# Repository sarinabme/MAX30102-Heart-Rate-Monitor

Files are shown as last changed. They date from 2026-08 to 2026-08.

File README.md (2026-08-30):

# Arduino Heart Rate Monitor❤️

> A real-time heart rate monitoring prototype using **Arduino UNO** and the **MAX30102 PPG sensor**.

<br>

## Overview

This project is an **Arduino-based heart rate monitoring prototype** developed using the **Arduino UNO** and the **MAX30102 optical pulse sensor**.

The system measures pulse signals using **photoplethysmography (PPG)**, calculates heart rate in **beats per minute (BPM)**, and displays the average measurement on a **16×2 I2C LCD**.

Based on **predefined BPM thresholds**, the measured heart rate is classified as **NORMAL**, **BRADYCARDIA**, or **TACHYCARDIA**. An audible **buzzer** provides feedback when the measured value falls outside the predefined normal range.

The prototype is designed as an **educational biomedical engineering project** to demonstrate the integration of **biosensors, microcontrollers, real-time signal acquisition, user feedback, and basic heart-rate classification**.

<br>

## 📸 Project Media

### 🧩 Hardware Setup

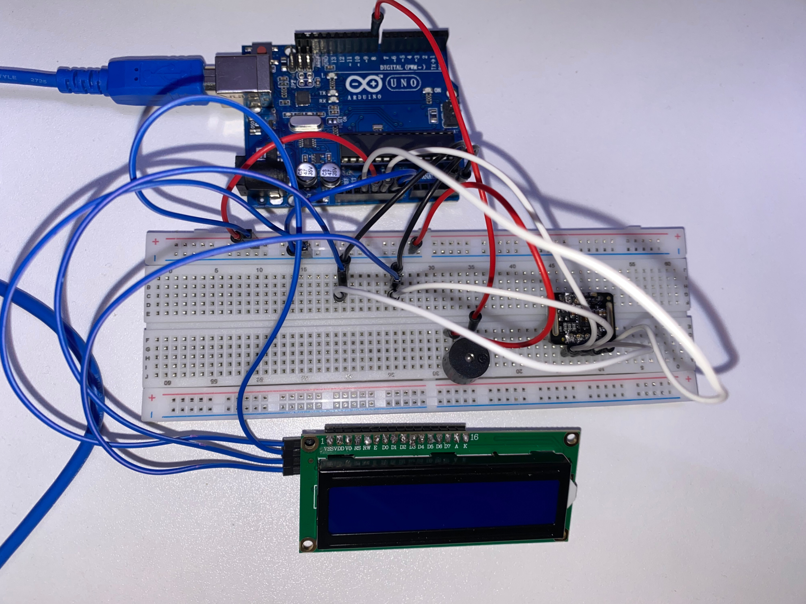
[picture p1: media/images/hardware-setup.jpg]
Hardware Setup


The complete prototype, including the **Arduino UNO, MAX30102 pulse sensor, 16×2 I2C LCD, buzzer, breadboard, and connecting wires**.

### ⚙️ System Initialization

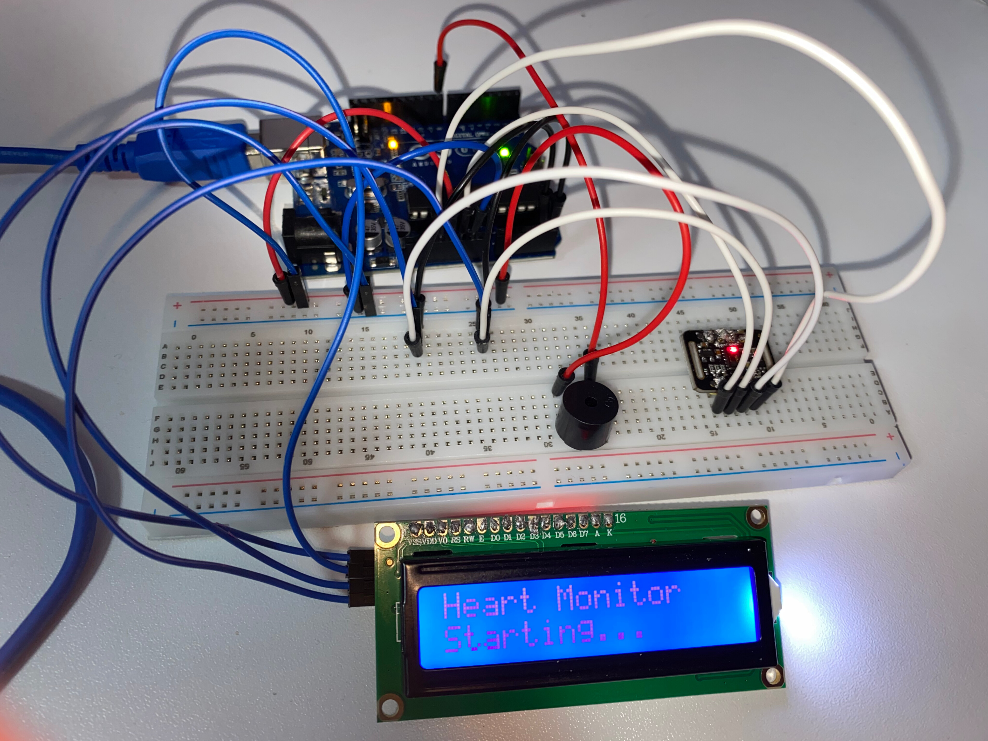
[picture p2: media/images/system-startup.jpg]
System Initialization


The system initializes the heart-rate monitoring hardware and prepares the sensor for measurement.

### ❤️ Real-Time Measurement

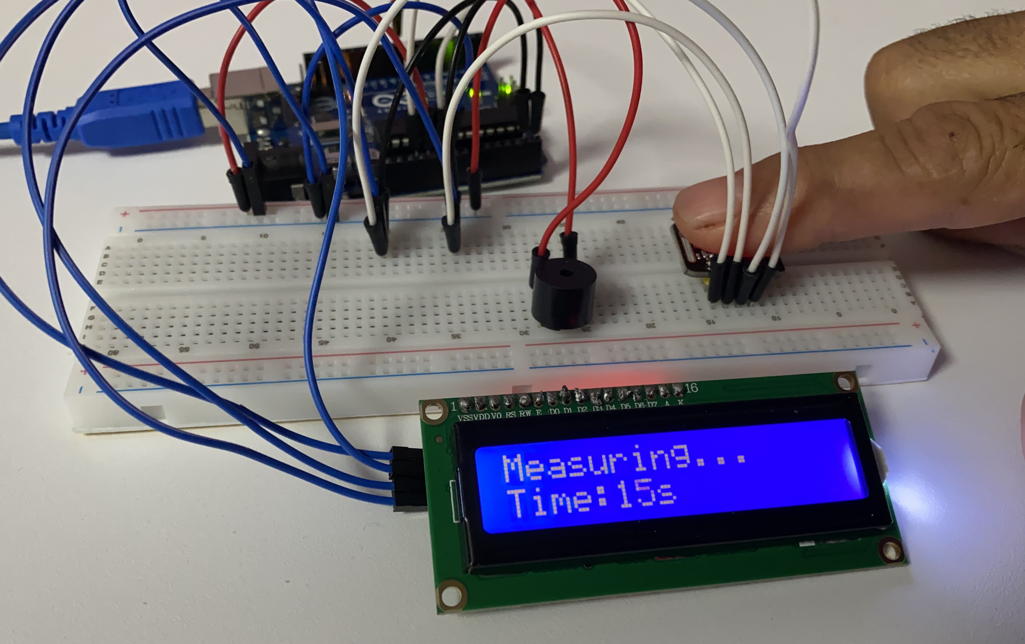
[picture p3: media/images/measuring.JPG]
Real-Time Measurement


During the measurement phase, the system continuously acquires pulse data while displaying the **remaining measurement time** on the LCD.

### 🔎 Data Analysis

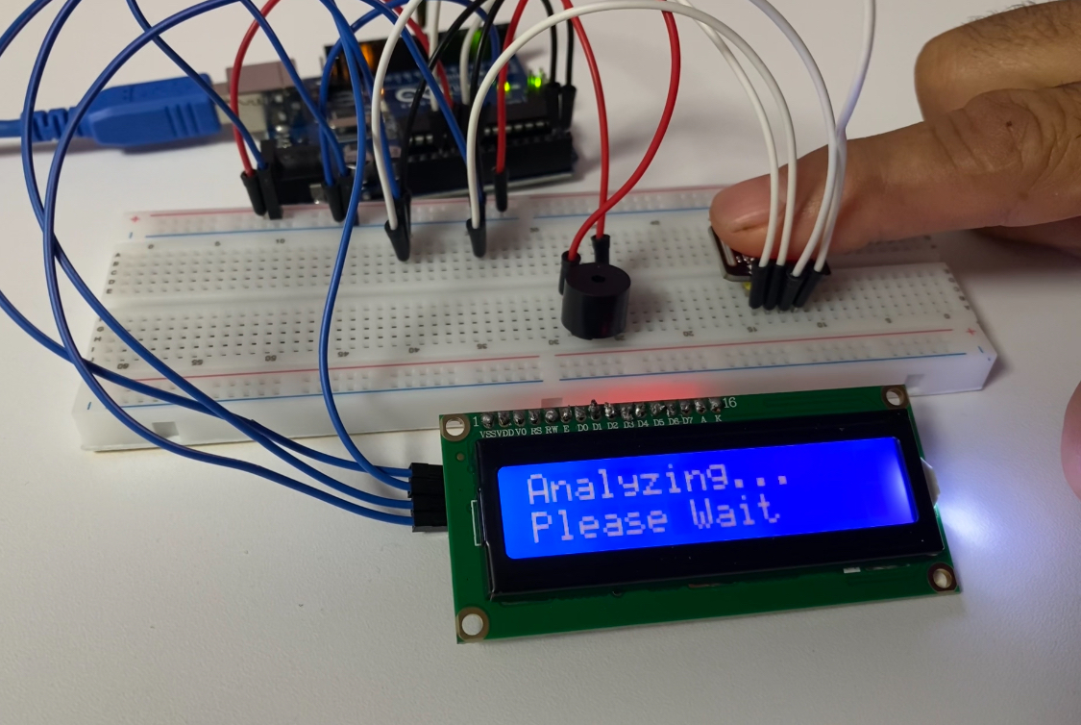
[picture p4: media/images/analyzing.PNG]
Data Analysis


After the **20-second measurement window**, the collected BPM data is processed to calculate the **average heart rate**.

### 📊 Normal Heart Rate Results

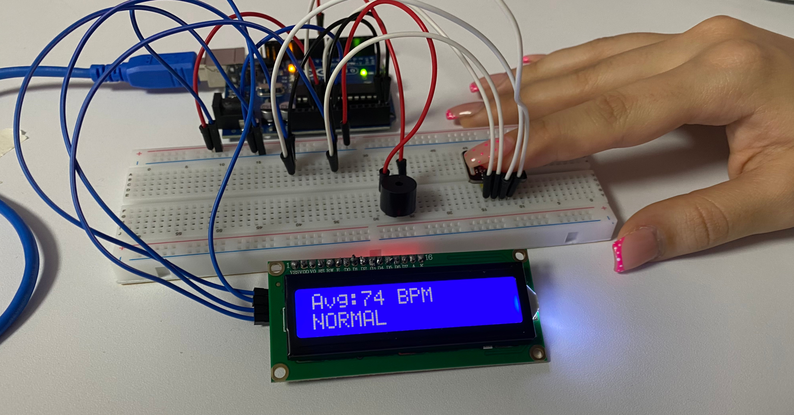
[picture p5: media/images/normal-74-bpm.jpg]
74 BPM Normal


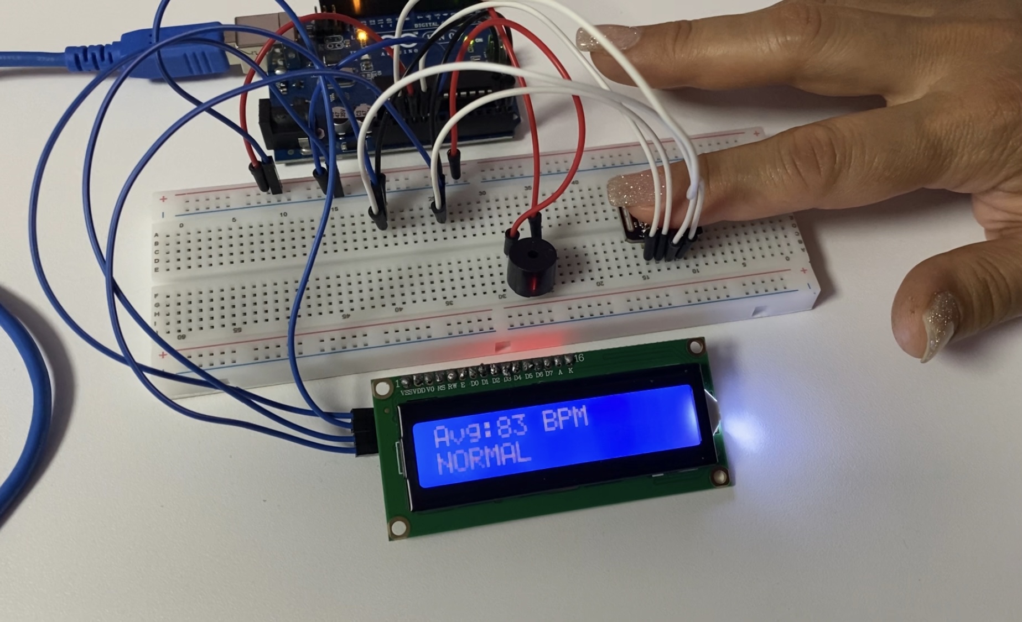
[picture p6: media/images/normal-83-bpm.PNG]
83 BPM Normal


Example measurements classified as **NORMAL** according to the predefined BPM thresholds implemented in the program.

### 🎥 Demonstration Videos

#### Bradycardia Detection

[▶️ Watch the Bradycardia Detection Demo](media/videos/bradycardia-detection.mp4)

Demonstration of a low heart-rate measurement resulting in a **`BRADYCARDIA`** classification and an audible **buzzer alert**.

#### Full Measurement Cycle

[▶️ Watch the Full Measurement Cycle](media/videos/full-measurement-cycle.mp4)

Demonstration of the measurement workflow, from **system initialization and finger detection** to **BPM calculation, classification, and test reset**.

#### No Reading Handling

[▶️ Watch the No Reading Demo](media/videos/no-reading-handling.mp4)

Demonstration of the system response when **no valid heart-rate measurement is obtained**.

<br>

## ✨ Features

*  **Real-Time Heart Rate Monitoring** using the MAX30102 optical pulse sensor
*  **BPM Calculation** from detected pulse intervals
*  **Average BPM Calculation** over a 20-second measurement window
*  **16×2 I2C LCD Display** for real-time system status and measurement results
*  **Measurement Countdown** displayed during the acquisition process
*  **Audible Feedback** using a buzzer for system status and heart-rate alerts
*  **Heart-Rate Classification** based on predefined BPM thresholds
*  **No Finger Detection** with a 30-second timeout
*  **No Reading Handling** when no valid BPM data is obtained
*  **Automatic Test Reset** with a countdown before starting a new measurement
*  **Serial Monitor Output** for debugging and BPM monitoring

<br>

## 🔧 Hardware

* **Arduino UNO** — Microcontroller
* **MAX30102** — Optical pulse sensor (PPG)
* **16×2 LCD** — User interface and result display
* **I2C Module** — Serial communication interface for the LCD
* **Buzzer** — Audible status and alert feedback
* **Breadboard** — Prototyping platform
* **Jumper Wires** — Electrical connections
* **Pin Headers** — Component connections
* **USB-B Cable** — Arduino power and programming

<br>

## 🧠 Architecture

The system follows a simple real-time acquisition and processing architecture.

The **MAX30102** captures optical pulse signals using photoplethysmography (PPG). The acquired data is processed by the **Arduino UNO**, which detects heartbeats, calculates BPM values, and computes the average heart rate over the measurement window.

The calculated result is then classified according to predefined BPM thresholds. The **16×2 I2C LCD** provides visual feedback throughout the measurement process, while the **buzzer** provides audible status and alert feedback.

### System Flow

**MAX30102 → Signal Acquisition → Beat Detection → BPM Calculation → Averaging → Heart-Rate Classification → LCD / Buzzer Output**

<br>

## ⚙️ How It Works

```text
System Initialization
        ↓
   Place Finger
        ↓
20-Second Measurement
        ↓
   Beat Detection
        ↓
   BPM Calculation
        ↓
    Averaging
        ↓
Heart-Rate Classification
        ↓
 LCD + Buzzer Output
        ↓
  New Test Countdown
```

<br>

## 📐 BPM Algorithm

The heart rate is estimated from the pulse signal acquired by the **MAX30102 PPG sensor**.

### Beat Detection

During the measurement window, the Arduino continuously reads the sensor's infrared (IR) signal. Individual heartbeats are detected using the `checkForBeat()` function provided by the MAX30102 heart-rate library.

When a heartbeat is detected, the system records its timestamp using `millis()`.

The time interval between two consecutive detected beats is calculated as:

**Δt = t₂ − t₁**

where:

* **t₁** = timestamp of the previous detected beat
* **t₂** = timestamp of the current detected beat
* **Δt** = time interval between consecutive beats in milliseconds

### Instantaneous BPM

The instantaneous heart rate is calculated from the beat-to-beat interval:

**BPM = 60,000 / Δt**

The factor **60,000** converts milliseconds to minutes.

Only calculated BPM values within the programmed range of **20–220 BPM** are accepted for averaging.

### Average BPM

During the **20-second measurement window**, all valid instantaneous BPM values are accumulated.

The final average is calculated as:

**Average BPM = Sum of valid BPM values / Number of valid BPM values**

If no valid BPM values are detected during the measurement period, the system displays:

`No Reading`

This approach provides a simple average of the detected beat-to-beat heart-rate estimates over the measurement window.

<br>

## ❤️ Heart Rate Classification

The calculated average BPM is classified using predefined thresholds implemented in the program.

| Average BPM  | Classification  | Buzzer |
| :---: | :--- | :--- |
|  **< 60 BPM**  | **BRADYCARDIA** | Continuous alert |
| **60–100 BPM** | **NORMAL** | Short confirmation beep |
|  **> 100 BPM** | **TACHYCARDIA** | Continuous alert |

The classification is based solely on the predefined BPM thresholds used in this prototype. It is intended for **educational demonstration and basic heart-rate classification**, not medical diagnosis.

### Classification Logic

```text
Average BPM
     │
     ├── < 60 ────────→ BRADYCARDIA
     │
     ├── 60–100 ──────→ NORMAL
     │
     └── > 100 ───────→ TACHYCARDIA
```

<br>

## 🔌 Wiring

The MAX30102 sensor and the 16×2 LCD communicate with the Arduino UNO through the **I²C interface**.

### Pin Connections

| Component | Pin | Arduino UNO |
| :--- | :----- | :---: |
| **MAX30102** | SDA | A4 |
| **MAX30102** | SCL | A5 |
| **MAX30102** | VCC | 3.3V |
| **MAX30102** | GND | GND |
| **16×2 I2C LCD** | SDA | A4 |
| **16×2 I2C LCD** | SCL | A5 |
| **16×2 I2C LCD** | VCC | 5V |
| **16×2 I2C LCD** | GND | GND |
| **Buzzer** | Signal | D8 |
| **Buzzer** | GND | GND |

### I²C Configuration

The LCD is initialized using the I²C address:

```cpp
LiquidCrystal_I2C lcd(0x27, 16, 2);
```

Both the MAX30102 and the LCD share the Arduino UNO's I²C bus through **SDA (A4)** and **SCL (A5)**.

> **Note:** The I²C address `0x27` is specific to the LCD I²C module used in this prototype and may differ between modules.

### Fritzing Wiring Diagram

The following diagram illustrates the complete hardware wiring of the prototype, including the Arduino UNO, MAX30102 sensor, 16×2 I2C LCD, buzzer, breadboard, power connections, and I2C communication lines.

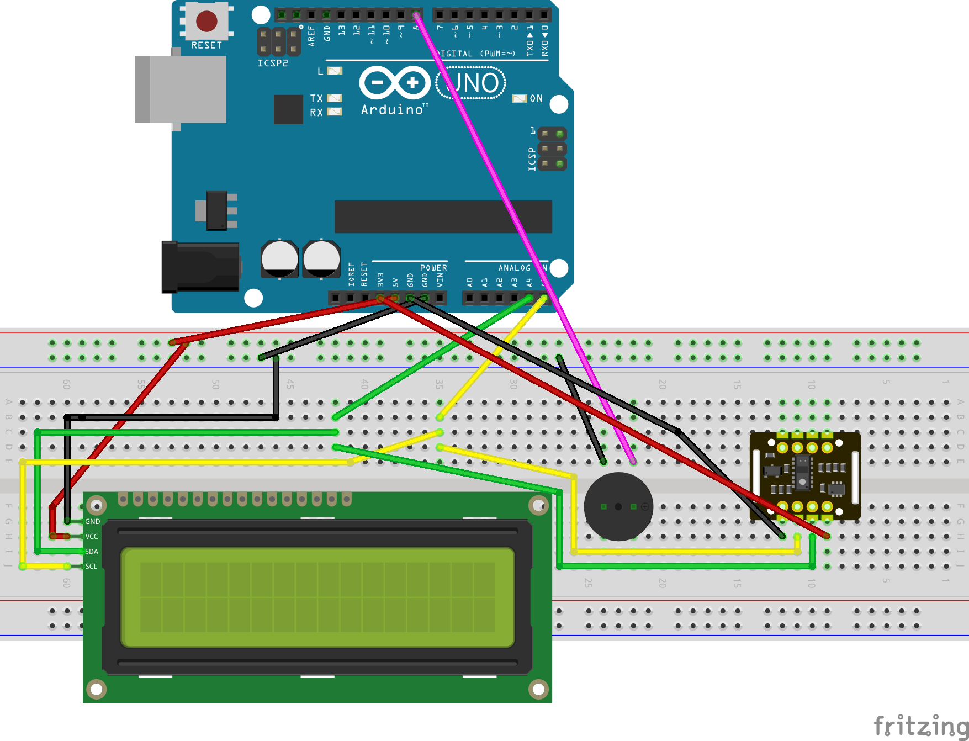
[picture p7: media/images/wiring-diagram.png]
Fritzing Wiring Diagram

<br>

## 💻 Installation

### 1. Install Arduino IDE

Install the **Arduino IDE** on your computer.

### 2. Connect the Arduino UNO

Connect the Arduino UNO to the computer using the **USB-B cable**.

### 3. Install Required Libraries

The project requires the following libraries:

* `Wire.h`
* `LiquidCrystal_I2C.h`
* `MAX30105.h`
* `heartRate.h`

`Wire.h` is included with the Arduino environment. The other libraries should be installed through the Arduino Library Manager or added manually if required.

### 4. Open the Project

Open the Arduino source file:

```text
src/HeartRateMonitor.ino
```

### 5. Select the Board and Port

In Arduino IDE:

**Tools → Board → Arduino UNO**

Then select the appropriate serial port under:

**Tools → Port**

### 6. Upload the Code

Compile and upload the program to the Arduino UNO.

After uploading, the system is ready for operation.

<br>

## ▶️ Usage

Follow these steps to perform a heart-rate measurement:

1. Power on the Arduino UNO.
2. Wait for the system initialization message.
3. When the LCD displays **`Place Finger / Ready...`**, place a finger gently on the MAX30102 sensor.
4. Wait for the short confirmation beep indicating that the finger has been detected.
5. Keep the finger stable during the **20-second measurement window**.
6. The LCD displays the remaining measurement time.
7. After measurement, the system displays **`Analyzing... / Please Wait`** while processing the collected data.
8. The final average BPM and classification are displayed on the LCD.
9. If the result is classified as **BRADYCARDIA** or **TACHYCARDIA**, the buzzer provides an audible alert.
10. After **7 seconds**, the system performs a **5-second countdown** and automatically prepares for a new measurement.

### Example LCD Flow

```text
Heart Monitor
Starting...
       ↓
Place Finger
Ready...
       ↓
Measuring...
Time: 15s
       ↓
Analyzing...
Please Wait
       ↓
Avg: 74 BPM
NORMAL
       ↓
New Test In
5 sec
```

<br>

## 🧪 Testing

The prototype was tested under several operating conditions to evaluate its basic functionality and response to different measurement scenarios.

| Test Case | Condition | Expected Behavior |
| :--- | :--- | :--- |
| **System Startup** | Arduino powered on | Display initialization message |
| **Finger Detection** | Finger placed on MAX30102 | Measurement begins |
| **No Finger** | No finger detected for 30 seconds | Display `No Finger / Try Again` |
| **Heart Rate Measurement** | Valid pulse signal detected | BPM values are calculated |
| **Normal Range** | Average BPM between 60–100 | Display `NORMAL` |
| **Low BPM** | Average BPM below 60 | Display `BRADYCARDIA` + buzzer alert |
| **High BPM** | Average BPM above 100 | Display `TACHYCARDIA` + buzzer alert |
| **Invalid Measurement** | No valid BPM obtained | Display `No Reading` |
| **Measurement Reset** | Test completed | 5-second countdown before new test |

These tests were designed to verify the main functional states implemented in the program, including normal operation, user interaction, abnormal classification, and basic error handling.

<br>

## 📊 Results

The prototype was successfully tested through multiple measurement scenarios. The observed outputs demonstrate the implemented measurement, classification, alert, and error-handling behaviors.

### Normal Measurements

Two example measurements produced results within the predefined normal range:

| Test | Average BPM | Classification |
| :--: | ---: | :--- |
| 1  |  **74 BPM** | **NORMAL** |
| 2  |  **83 BPM** | **NORMAL** |

### Low Heart-Rate Classification

Additional tests produced:

| Test | Average BPM | System Classification |
| :--: | ---: | :--- |
| 3  |  **58 BPM** | **BRADYCARDIA** |
| 4  |  **27 BPM** | **BRADYCARDIA** |

In both cases, the buzzer was activated according to the programmed alert logic.

### No Reading Test

A separate test resulted in:

```text
Analyzing...
Please Wait
        ↓
No Reading
```

This demonstrates that the system does not display an average BPM when no valid heart-rate data is obtained.

> **Important:** The values above represent prototype measurements and software classifications. They should not be interpreted as clinical measurements or medical diagnoses.

<br>

## ⚠️ Limitations

As an educational prototype, the system has several technical and practical limitations:

1. **Motion Artifacts**
   Finger movement can introduce artifacts into the PPG signal and may affect beat detection and BPM estimation.

2. **Finger Placement**
   Incorrect or inconsistent finger placement on the MAX30102 may reduce signal quality and affect the measurement.

3. **Ambient Light**
   External light conditions may influence optical measurements and reduce signal reliability.

4. **Short Measurement Window**
   The system uses a **20-second measurement window**, which is suitable for demonstrating the prototype but is not sufficient for comprehensive or long-term clinical monitoring.

5. **Simple Threshold Classification**
   The classification is based only on average BPM thresholds. The system does not analyze **ECG morphology, arrhythmias, heart-rate variability, or rhythm irregularities**.

6. **PPG-Based Measurement**
   The system relies on an optical PPG sensor rather than ECG-based cardiac electrical measurements.

7. **Prototype-Level Signal Processing**
   The current implementation uses a relatively simple beat-detection and averaging approach and does not include advanced filtering or comprehensive signal-quality assessment.

8. **Sensor and Hardware Limitations**
   Measurement accuracy can be affected by sensor characteristics, hardware configuration, environmental conditions, and user interaction.

<br>

## 🩺 Medical Disclaimer

**This project is an educational prototype designed for heart-rate monitoring and basic heart-rate classification. It is not a medical device and must not be used for diagnosis, treatment, or clinical decision-making. The displayed results may be affected by motion, finger placement, ambient light, and sensor limitations.**

<br>

## 🚀 Future Work

The prototype can be further improved through the following developments:

* **Motion Artifact Reduction** — Improve robustness against finger movement and motion-related signal artifacts.
* **Digital Filtering** — Apply digital filters to improve PPG signal quality and reduce noise.
* **Signal Quality Assessment** — Evaluate the quality and reliability of the acquired pulse signal before calculating BPM.
* **Automatic Sensor Recovery** — Improve system recovery when the sensor becomes disconnected or produces invalid data.
* **Data Logging** — Store measurements for later analysis and visualization.
* **Advanced Heart-Rate Analysis** — Explore additional features such as heart-rate variability and rhythm analysis.
* **Improved Display Interface** — Replace the 16×2 LCD with a higher-resolution display such as an OLED.
* **Wireless Connectivity** — Add Bluetooth connectivity for transferring measurements to another device.
* **PC/Mobile Visualization** — Develop a graphical interface for real-time monitoring and historical data visualization.

<br>

---

### 👩‍💻 Author

**Developed by Sarina Jou**

### 📄 License

This project is licensed under the **MIT License** and is intended for educational and research purposes.

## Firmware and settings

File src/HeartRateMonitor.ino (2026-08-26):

#include <Wire.h>
#include <LiquidCrystal_I2C.h>
#include "MAX30105.h"
#include "heartRate.h"

MAX30105 particleSensor;
LiquidCrystal_I2C lcd(0x27, 16, 2);

const int buzzerPin = 8;

const unsigned long MEASURE_TIME = 20000;
const unsigned long RESULT_TIME = 7000;
const unsigned long FINGER_TIMEOUT = 30000;

unsigned long lastBeat = 0;
float beatsPerMinute = 0;

void setup()
{
  Serial.begin(115200);

  pinMode(buzzerPin, OUTPUT);
  noTone(buzzerPin);

  lcd.init();
  lcd.backlight();

  lcd.setCursor(0, 0);
  lcd.print("Heart Monitor");
  lcd.setCursor(0, 1);
  lcd.print("Starting...");

  if (!particleSensor.begin(Wire, I2C_SPEED_STANDARD))
  {
    lcd.clear();
    lcd.setCursor(0, 0);
    lcd.print("MAX30102 Error");

    Serial.println("MAX30102 not found!");

    while (1)
      ;
  }

  particleSensor.setup();

  particleSensor.setPulseAmplitudeRed(0x0A);
  particleSensor.setPulseAmplitudeGreen(0);

  delay(2000);

  lcd.clear();
}

void loop()
{
  noTone(buzzerPin);

  lcd.clear();
  lcd.setCursor(0, 0);
  lcd.print("Place Finger");
  lcd.setCursor(0, 1);
  lcd.print("Ready...");

  unsigned long fingerStartTime = millis();

  while (particleSensor.getIR() < 50000)
  {
    if (millis() - fingerStartTime >= FINGER_TIMEOUT)
    {
      lcd.clear();
      lcd.setCursor(0, 0);
      lcd.print("No Finger");
      lcd.setCursor(0, 1);
      lcd.print("Try Again");

      Serial.println("No finger detected.");

      delay(3000);
      return;
    }

    delay(100);
  }

  tone(buzzerPin, 2000, 200);

  float bpmSum = 0;
  int bpmCount = 0;

  unsigned long startTime = millis();

  lastBeat = 0;
  beatsPerMinute = 0;

  while (millis() - startTime < MEASURE_TIME)
  {
    long irValue = particleSensor.getIR();

    int remain =
        (MEASURE_TIME - (millis() - startTime)) / 1000;

    lcd.setCursor(0, 0);
    lcd.print("Measuring...   ");

    lcd.setCursor(0, 1);
    lcd.print("Time:");
    lcd.print(remain);
    lcd.print("s    ");

    if (checkForBeat(irValue))
    {
      unsigned long currentTime = millis();

      if (lastBeat != 0)
      {
        unsigned long delta = currentTime - lastBeat;

        if (delta > 0)
        {
          beatsPerMinute = 60000.0 / delta;

          if (beatsPerMinute > 20 && beatsPerMinute < 220)
          {
            bpmSum += beatsPerMinute;
            bpmCount++;

            Serial.print("BPM: ");
            Serial.println(beatsPerMinute);
          }
        }
      }

      lastBeat = currentTime;
    }
  }

  lcd.clear();
  lcd.setCursor(0, 0);
  lcd.print("Analyzing...");
  lcd.setCursor(0, 1);
  lcd.print("Please Wait");

  delay(1500);

  lcd.clear();

  if (bpmCount == 0)
  {
    lcd.setCursor(0, 0);
    lcd.print("No Reading");
    delay(3000);
    return;
  }

  int avgBPM = bpmSum / bpmCount;

  lcd.setCursor(0, 0);
  lcd.print("Avg:");
  lcd.print(avgBPM);
  lcd.print(" BPM");

  lcd.setCursor(0, 1);

  if (avgBPM < 60)
  {
    lcd.print("BRADYCARDIA");

    tone(buzzerPin, 1000);

    Serial.println("Status: LOW HEART!");
  }
  else if (avgBPM > 100)
  {
    lcd.print("TACHYCARDIA");

    tone(buzzerPin, 1000);

    Serial.println("Status: HIGH HEART!");
  }
  else
  {
    lcd.print("NORMAL");

    noTone(buzzerPin);

    Serial.println("Status: NORMAL");

    tone(buzzerPin, 2500, 150);
  }

  Serial.print("Average BPM = ");
  Serial.println(avgBPM);

  delay(RESULT_TIME);

  noTone(buzzerPin);

  for (int i = 5; i > 0; i--)
  {
    lcd.clear();

    lcd.setCursor(0, 0);
    lcd.print("New Test In");

    lcd.setCursor(0, 1);
    lcd.print(i);
    lcd.print(" sec");

    delay(1000);
  }

  lcd.clear();
}
